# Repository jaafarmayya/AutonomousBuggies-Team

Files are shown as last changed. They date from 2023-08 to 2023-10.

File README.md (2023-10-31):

# WRO2023 FUTRE ENGINEERS - Autonomous Robot Vehicle

This repository presents a detailed description about the autonomous robot vehicle used by team 'Autonomous Buggies' in the aim of participating in WRO2023 competetion - Future Engineers category. 
The mechanical, electrical, and electronic parts of the vehicle are well described and provided. The source codes used to program the vehicle are written in Python and Arduino C. Additionally, a detailed explanation of the algorithms and mathematical principles is provided to help everyone learn. All these details can be found the sections listed below:

---

## Introduction

This Repository contains all necessary information to entirely build a self driving car, which is capable of completing three laps and
handling different configurations of the obstacles. The code is divided into two main parts, one written with python programming language, which is responsible for image processing and sending made decision to the arduino via Serial communication ([Python code](https://github.com/jaafarmayya/AutonomousBuggies-Team/tree/main/src/Obstacle%20Challenge/Python)). And one written with Arduino C programming language, which is responsible for controlling the motors movement based on the different sensors reading and recieved decision ([Arduino code](https://github.com/jaafarmayya/AutonomousBuggies-Team/tree/main/src)). The rest of the readme.md file explains in deteails each of the following:

- [Software Setup](#SoftwareSetup)
- [Mobility Management](#MobilityManagement)
- [Obstacle Management](#ObstacleManagement)
- [Power and Sense Management](#PowerandSenseManagement)

---

## Software Setup 

Before using the robot, software should be configured first, you will need to install the following (Programs have been tested and configured with both Windows 10 and Windows 11 operating systems. In case of using another operating system, we strongly recommend using any available searching engine to search for the installation for the software by yourself).
We'll be using Raspberry Pi to run image processing code written in python programming language. Commands will be sent via Serial communication to arduino wich will control the motors.

### Raspberry Pi Preparation and Configuration
In this section, we will go through all the steps to prepare and configure your Raspberry Pi. After completing the steps, you will be able to access your Raspberry Pi remotely and control it.
#### Raspberry Pi Operating System 
There are a lot of OS systems for Raspberry Pi with different versions. You can choose any of them from [official site](https://www.raspberrypi.com/software/operating-systems/), but it is preferable to install the same version we installed since it is tested and it works fine ([download link](https://downloads.raspberrypi.com/raspios_full_arm64/images/raspios_full_arm64-2023-02-22/2023-02-21-raspios-bullseye-arm64-full.img.xz)).
#### Raspberry Pi Imager installation
You will be setting up Raspberry Pi OS on your Raspberry Pi using the Raspberry Pi Imager tool, it will allow you to flash the image onto a USB flash drive. The provided steps cover the installation process, initial configuration, and essential steps to get your Raspberry Pi up and running. 
Using the Raspberry Pi Imager tool to flash the Raspberry Pi OS image onto a USB flash drive offers a convenient and efficient way to set up your Raspberry Pi. The Imager simplifies the installation process by providing a user-friendly interface to select the operating system and target storage medium. With just a few clicks, you can download the official Raspberry Pi OS image and write it directly to the USB flash drive. This eliminates the need for manual installation and configuration, saving you time and effort.
- To install Raspberry Pi Imager, Visit the official Raspberry Pi website at https://www.raspberrypi.org/software/.
- Download the Raspberry Pi Imager tool suitable for your operating system (Windows, macOS, or Linux).
- Install Raspberry Pi Imager on your computer by following the provided instructions.
####Flashing the Raspberry Pi OS Image to USB
After downloading Raspberry Pi OS and installing the Imager, you can flash the OS Image to your USB (SD card can also be used):
 - Launch Raspberry Pi Imager on your machine.
 - In the Raspberry Pi Imager window, click on "Choose OS" button.
 - Click on "Use custom" option, then navigate to the directory of the OS that was previously downloaded.
 - Click on "Choose  Storage" option, in the file explorer window select your USB flash drive as the target storage medium.
 - The widnow should have the same configuration as the image below after choosing the flash drive and OS:
     
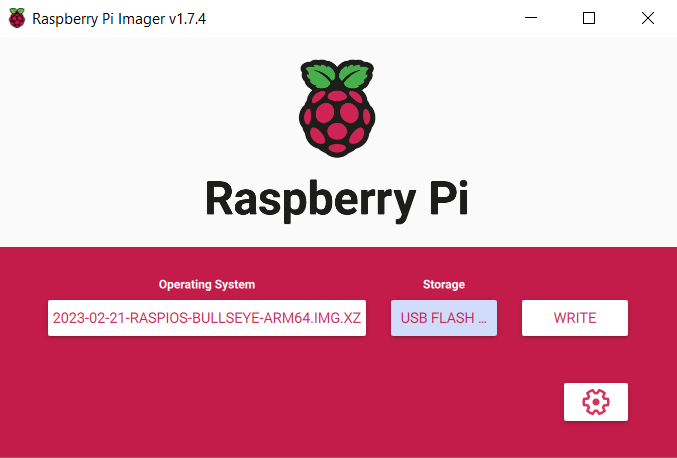
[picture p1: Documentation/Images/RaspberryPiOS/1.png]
      <p align="center" Style="font-size:12px; color:grey; font-type:italic;"><i> Figure 1: RaspberryPi Imager </i></p>

 - Now click on the settings icon in the bottom right corner, you will need to enable the SSH option and choose a username and a password (This is necessary because you will use SSH to establish a connection between your device and Raspberry Pi, it will allow you to control the Raspberry Pi remotely).

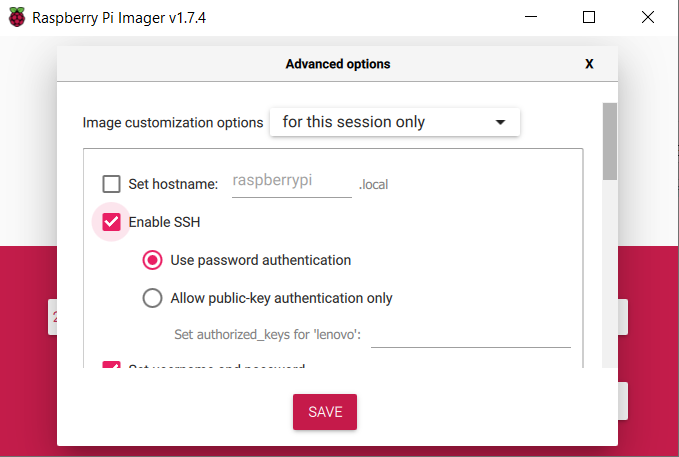
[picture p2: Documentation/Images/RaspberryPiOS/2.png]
  <p align="center" Style="font-size:12px; color:grey; font-type:italic;"><i> Figure 2: RaspberryPi SSH connection enabling </i></p>
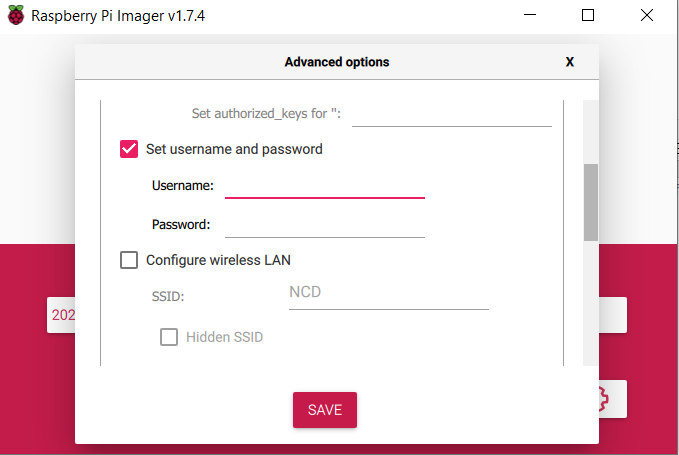
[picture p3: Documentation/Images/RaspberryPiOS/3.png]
  <p align="center" Style="font-size:12px; color:grey; font-type:italic;"><i> Figure 3: RaspberryPi username and password </i></p>

- Next, you will need to enter the name of your network and its password, this will allow you to access the Raspberry pi directly and remotely.
   
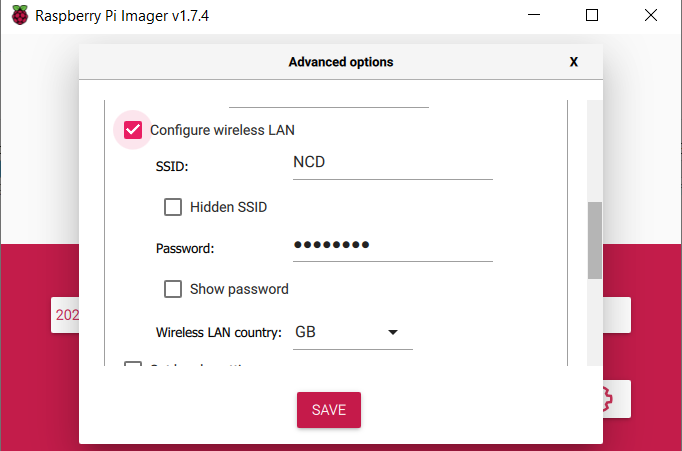
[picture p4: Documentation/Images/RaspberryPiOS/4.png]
   <p align="center" Style="font-size:12px; color:grey; font-type:italic;"><i> Figure 4: RaspberryPi network configuration </i></p>

- Click on the "Write" button to start the flashing process. Raspberry Pi Imager will download the latest Raspberry Pi OS image and write it to the USB flash drive. This process may take several minutes, depending on your machine.
Once the flashing process is completed, Raspberry Pi Imager will display a success message.

### Raspberry Pi Remote Connection configuration
There three ways to control Raspberry Pi:
- Use a mouse, a monitor and a keyboard attached to your Raspberry Pi.
- Use ethernet cable attached to your machine and Raspberry Pi, and a virutal machine software.
- Connect both Raspberry Pi and your machine to the same network, and use a virtual machine software.

we will be using the third option since it is be a lot easier to control your Raspberry Pi remotely.
1. To control and access the Raspberry Pi, you will need a program to establish wireless connection. MobaXterm is the program that will allow you to establish this communication, which is based on SSH protocol.
 - Download the program from this [link]( https://mobaxterm.mobatek.net/download-home-edition.html), choose portable edition.
 - After succefully downloading the software, extract the contents of the downloaded file to a specified folder.
 - The program is ready to be used now, when launching it, a window like that will appear (it should be noted that both the raspberry pi and your device have to be connected to the same network):

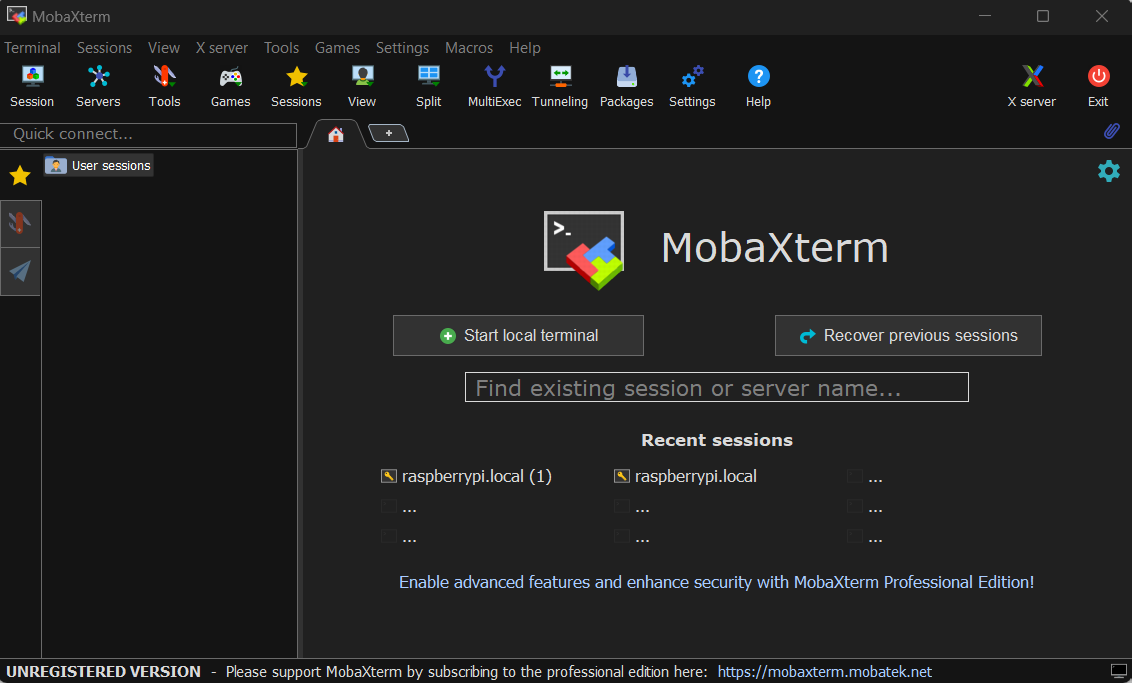
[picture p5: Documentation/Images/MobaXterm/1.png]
MobaXterm
   <p align="center" Style="font-size:12px; color:grey; font-type:italic;"><i> Figure 5: MobaXterm Interface </i></p>

 - Choose Session tab in the top left corner:

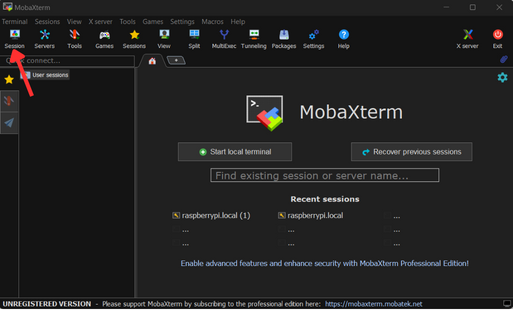
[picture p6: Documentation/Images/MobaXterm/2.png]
Session Option
   <p align="center" Style="font-size:12px; color:grey; font-type:italic;"><i> Figure 6: Choosing new session </i></p>

 - A new window will appear that contains the settings of the new connection:

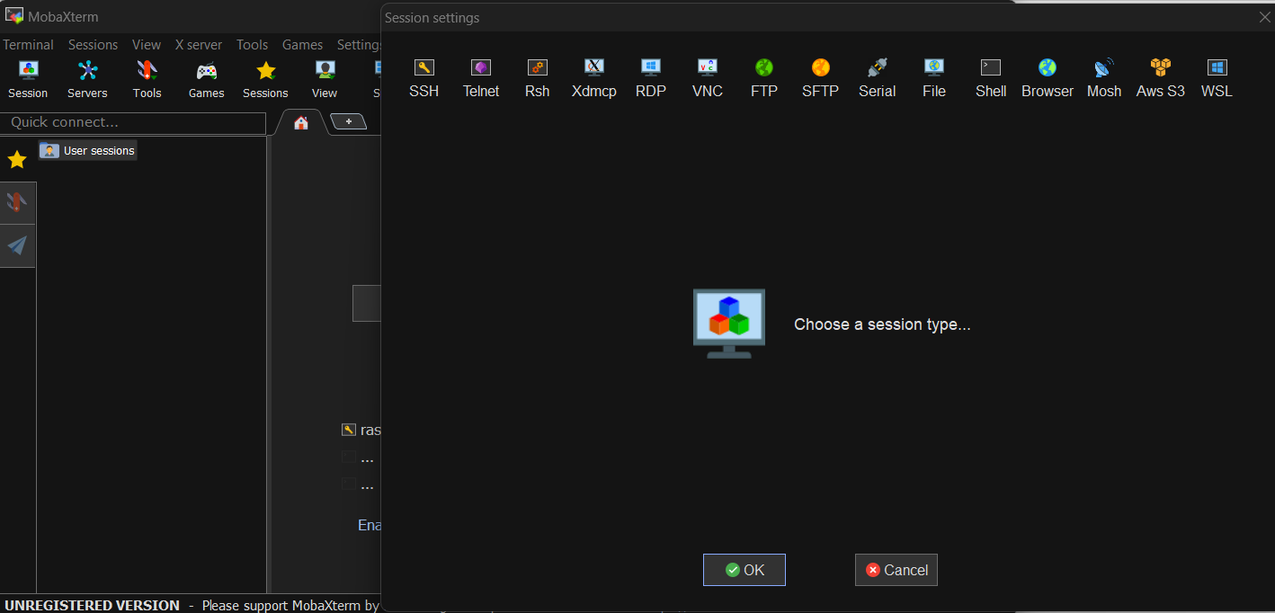
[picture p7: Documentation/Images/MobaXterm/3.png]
Session window
   <p align="center" Style="font-size:12px; color:grey; font-type:italic;"><i> Figure 7: new session tab </i></p>

 - Click on the SSH icon, we will be using SSH in our work. SSH (Secure Shell) is a network protocol that provides a secure way to access and manage remote systems. It allows to establish a secure encrypted connection between local computer and a remote device, such as a Raspberry Pi in our case.Using SSH to access a Raspberry Pi offers several advantages, as it allows remote access to the Raspberry Pi's command-line interface, providing a convenient and efficient way to manage and configure the device. Through an SSH connection, commands can be executed, files can be transfered, perform system administration tasks without the need for physical access to the Raspberry Pi. Moreover, SSH is particularly useful for headless Raspberry Pi setups, where the device is not connected to a monitor or keyboard. In such cases, SSH enables remote administration, making it possible to configure and control the Raspberry Pi over the network from a different computer.

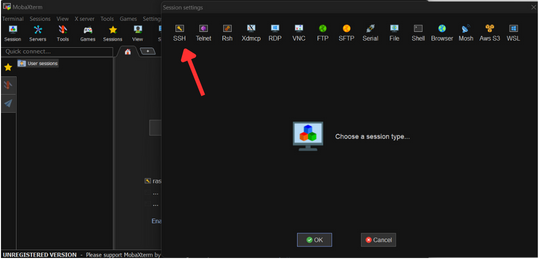
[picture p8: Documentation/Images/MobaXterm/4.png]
SSH
   <p align="center" Style="font-size:12px; color:grey; font-type:italic;"><i> Figure 8: choosing SSH communication  </i></p>

- To establish a connection with the Raspberry Pi, remte host name will be needed, which will be raspberrypi.local (The IP of the Raspberry Pi can also be used, but the domain name raspberrypi.local will work fine). With current Configuration, all commands will be executed through the terminal, to make these operations easier, LXDE desktop will be used as GUI as in the image below:

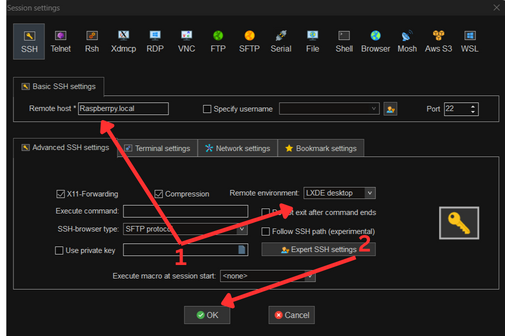
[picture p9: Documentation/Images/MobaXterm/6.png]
   <p align="center" Style="font-size:12px; color:grey; font-type:italic;"><i> Figure 9: Remote Host and LXDE Desktop</i></p>

- Now the settings are ready, click ok and it will need the username and password that was set during the setup of the raspberrypi py operating system:

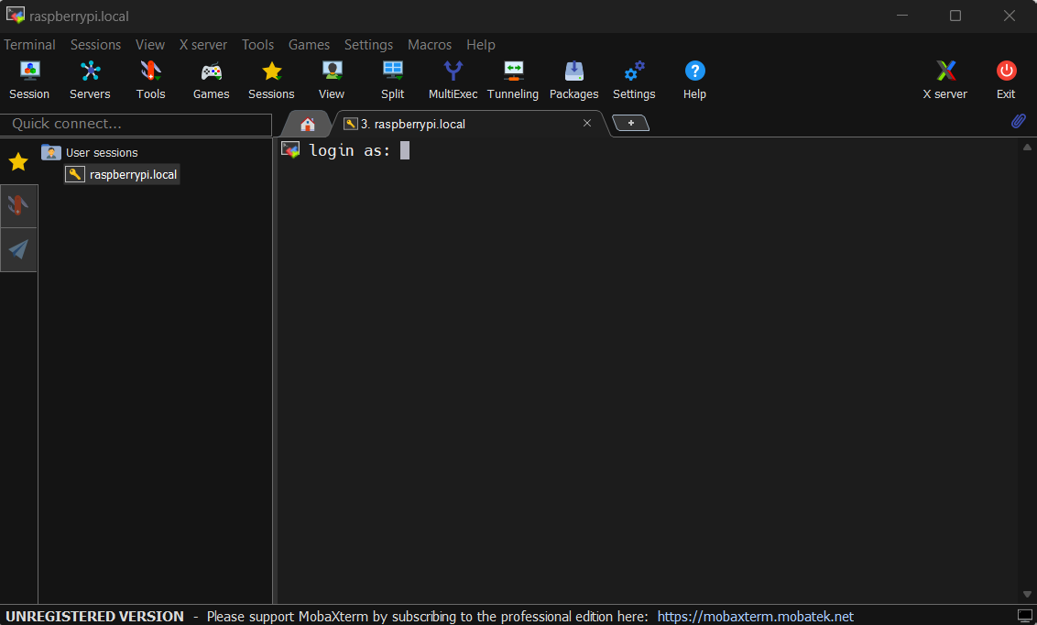
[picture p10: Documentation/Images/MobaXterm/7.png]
   <p align="center" Style="font-size:12px; color:grey; font-type:italic;"><i> Figure 10:Login window </i></p>

- After applying the previous steps, connection is succefully established and Raspberry Pi is ready to be used remotely, a new LXDE desktop window will be opened, all subsequent work will be done here:
  
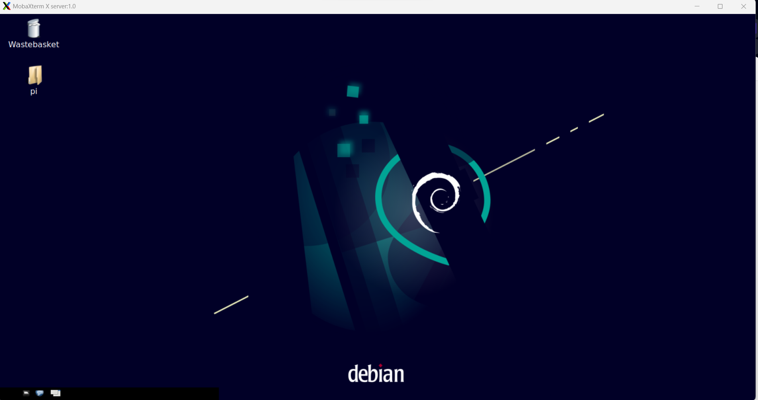
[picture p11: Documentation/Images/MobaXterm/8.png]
   <p align="center" Style="font-size:12px; color:grey; font-type:italic;"><i> Figure 11: RaspberryPi LXDE desktop </i></p>

- Update Raspberry Pi, enter the following commands in order, this step make take some time:

   1- ```sudo apt update``` 

   2- ```sudo apt upgrade```

### Raspberry Pi Camera Activation

- One last step is to turn on Raspberry Pi camera. Write the command below in the terminal:

   ```sudo raspi-config```

- The window of Raspberry Pi settings will be opened, use arrow keys to move the cursor between the options. Choose the option with label "Interfacing Options" by pressing "Enter" key:

  ![MobaXterm](/Documentation/Images/RaspberryPiOS/cam1.png)<p align="center" Style="font-size:12px; color:grey; font-type:italic;"><i> Figure 12: Interfacing Options </i></p>

- Now choose camera and press "Enter", the camera is activated now.
  
    ![MobaXterm](/Documentation/Images/RaspberryPiOS/cam2.png)

    ![MobaXterm](/Documentation/Images/RaspberryPiOS/cam3.png)<p align="center" Style="font-size:12px; color:grey; font-type:italic;"><i> Figure 13+14:Choosing camera option </i></p>

- After finishing the previous steps, press "ESC" to return to the original terminal, and enter the command below:
 
  ```sudo reboot```

### Installing Arduino IDE on Raspberry Pi

- Arduino IDE installation steps are straightforward. Open the terminal by clicking on the terminal icon or by using the shortcut Ctrl+Alt+T, then enter the following command:

   ```sudo apt install arduino```

- Before using the IDE, setting the permissions for the Arduino port in Raspberry Pi is needed:
Connect the Arduino to the Raspberry Pi using a USB cable. In the terminal on the Raspberry Pi, type the following command to list the available ports on your Raspberry Pi:
  
   ```ls /dev/tty*```

- This command will display a list of devices, and the Arduino port should be listed as something like `/dev/ttyACM0` or `/dev/ttyUSB0`. Note down the port name as you will need it for the next step. By default, the serial ports in Raspberry Pi are not accessible to regular users. To grant access to the Arduino port, you can use the chmod command to change the permissions of the port. Run the following command, replacing /dev/ttyACM0 with the actual port name you obtained:

   ```sudo chmod a+rw /dev/ttyACM0```

- After running the chmod command, you should now have the necessary permissions to access the Arduino port, and you are ready to use the arduino with the raspberry pi. To use the Arduino IDE, you can easily access it in the programming tab as in the image below:
   
   ![Settings Configuration](/Documentation/Images/MobaXterm/34.png)<p align="center" Style="font-size:12px; color:grey; font-type:italic;"><i> Figure 15:Open programming tab and click Arduino icon </i></p>

- A window will open like the one below:

   ![Settings Configuration](/Documentation/Images/MobaXterm/11.png)<p align="center" Style="font-size:12px; color:grey; font-type:italic;"><i> Figure 16:Ardunio IDE interface</i></p>

### Downloading OpenCV PySerial library

- PySerial library is essntial component to establish a succeful connection between Arduino and Raspberry Pi, it can be easily downloaded using the following command below:

   ```sudo apt-get install python-serial```

### Downloading OpenCV library on Raspberry Pi

We will be using OpenCV library, which stands for (Open Source Computer Vision Library). OpenCV is a popular open-source computer vision and machine learning library. It provides a vast collection of functions and algorithms for image and video processing, object detection and tracking, feature extraction, and more.

- OpenCv library isn't installed by default on the Raspberry Pi, you will have to install it. Open the terminal, and type the following command:

   ``` sudo apt-get install python3-opencv```
- Wait till the installation is done, when it is done, open any code editor, which can be found in the programming tab:
  
     ![Settings Configuration](/Documentation/Images/MobaXterm/34.png)<p align="center" Style="font-size:12px; color:grey; font-type:italic;"><i> Figure 17:Open programming tab and click Geany icon</i></p>

- Choose Geany code editor for example. Geany is a simple and easy to use code editor (Try searching the internet for more details in case you want to know more), a window like this will be opened:
  
     ![Settings Configuration](/Documentation/Images/MobaXterm/9.png)<p align="center" Style="font-size:12px; color:grey; font-type:italic;"><i> Figure 18:Geany editor interface </i></p>

- Import the library using the following command, and you are ready to use the library:

   ```import cv2```

---

##Mobility Management 

### Vehicle Main Body
The vehicle main body is built using `LEGO`, building instructions are available [here](https://github.com/jaafarmayya/AutonomousBuggies-Team/blob/main/models/Building%20Instructions.rar).
The main Micrprocessor in the vehicle is `Raspberry Pi 4 Model b` provided with `Raspberry pi Camera V2.1`.
Main Macrocontroller is Atmega mounted on `Arudino Mega 2560` board.
To ensure the accurate and efficient control and direction of the vehicle’s movement, we employed two crucial components:
- **Servo Motor Model**
- **J Sumo DC Motor**
- **BTS7960 Motor Driver**

The servo motor model was selected for controlling the vehicle’s steering, while the BTS7960 motor driver is utilized to control the movement of J Sumo DC motor in order to provide the necessary power to drive the vehicle’s motion. 

### The Motion Mechanism 
We used Direct-Acting steering and to achieve that a servo motor was installed in way that can move the steering mechanism freely, while the DC motor (J Sumo 1000 rpm) serves as the driving motor. The kinetic energy generated by the DC motor is transferred to the back wheels through a differential gearbox. The wheels receive this energy via a drive shafts of LEGO components, which transmits torque to the differential gearbox through a suitable coupler [model](https://github.com/jaafarmayya/AutonomousBuggies-Team/blob/main/models/Coupler.jpg).

### Steering Mechanism

Our design incorporates front Direct-Acting Steering, a mechanism that eliminates the need for a steering gear by connecting the steering wheel directly to the steering linkage. Our front direct-acting steering method offers several advantages over conventional steering systems:

**A.Enhanced Responsiveness:**
The direct connection between the steering wheel and the steering linkage results in immediate and precise response to servo's input (angle), providing enhanced control and maneuverability.

 **B.Reduced Complexity:**
Our steering method simplifies the overall design, reducing weight and complexity, and potentially lowering manufacturing and maintenance costs.

**C. Lower Maintenance Requirements:**
 With fewer components involved, the direct-acting steering method can reduce the need for maintenance and potential points of failure, resulting in improved reliability and durability.
The mechanism of our front direct-acting steering method can be summarized as follows:

**-  Steering Input Translation:**
 When the servo motor turns the steering axle, the input is directly transmitted to the steering linkage, causing the front wheels to turn accordingly.

**-  Cornering:**
 During cornering, the steering mechanism maintain a smooth trajectory based on the servo motor input.

![Direct Acting Steering](/Documentation/Images/Steering+Mechanism/Picture1.jpg)

![Direct Acting Steering](/Documentation/Images/Steering+Mechanism/SteeringMechanism.jpg)<p align="center" Style="font-size:12px; color:grey; font-type:italic;"><i> Figure 19:Direct Acting Steering </i></p>

When designing a steering mechanism, some parameters should be considered to measure the characteristics and specifications of the steering system:

**1. Steering Ratio**

It is a key parameter in a steering system that describes the relationship between the rotation of the steering wheel (which is servo axle in our case) and the resulting rotation of the wheels. Moreover, it quantifies the mechanical advantage or amplification provided by the steering mechanism.
Mathematically speaking, it is defined as the ratio of the angle turned by the steering wheel (servo axle) θ<sub>servo</sub> 
to the angle turned by the wheels θ<sub>wheels</sub> , in the direct acting steering θ<sub>wheels</sub> is equal to θ<sub>servo</sub>.
It can be expressed as:

$\theta _{servo} =  \theta _{wheels}  \Rightarrow Steering Ratio =  \frac{\theta _{servo}}{\theta _{wheels}} = 1$

The steering ratio determines how much the wheels will turn in response to a given rotation of the servo. A higher steering ratio means that a smaller rotation of the steering wheel will result in a larger rotation of the wheels, providing a greater turning effect. Conversely, a lower steering ratio means that a larger rotation of the steering wheel is required to achieve the same wheel rotation. So, it can be described as a measure of the sensitivity and responsiveness of the steering system.

**2. Steering Wheel Torque**
 
Steering wheel torque T<sub>wheels</sub>
is the influence of servo motor force or moment applied on the steering. In other words, it refers to the force or moment applied to the wheels as a result of the torque output from the servo motor.
T<sub>wheels</sub> can be calculated by multiplying the applied force by servo motor F<sub>servo</sub> by the effective lever arm or steering arm length L<sub>eff</sub> which is the distance between the point where the force is applied and the axis of rotation of the steering wheel: 

$T_{wheel} =  F_{servo}  \times L_{eff}$

When interpreting the steering wheel torque, it should be noted that a higher steering wheel torque indicates that more force is needed from the servo motor to turn the steering wheel, providing a greater resistance to steering. Conversely, a lower steering wheel torque implies that less force is required, resulting in lighter and easier steering.

**3. Steering Wheel angle**

The steering wheel angle refers to the angle of rotation of the servo motor's output shaft, which is directly connected to the steering mechanism of the robot. Furthermore, it represents the angular displacement of the servo motor's output shaft from its neutral or reference position. 
This angle determines the orientation of the robot's steering mechanism and thus influences the robot's movement and direction.

$\theta_{wheel} =  \theta_{motor}  \times Steering Ratio$

---

### Differential Gear
Differential gear is a crucial component in our robot that allows the rear-wheels to rotate at different speeds at the same time while maintaining power distribution. The primary function of the differential gear is to enable the wheels on the same axle to rotate at different speeds when the robot is turning or when there is a difference in traction between the two wheels. It distributes torque from the engine to the wheels while allowing them to rotate at varying speeds. Our differential gear consists of several components:
- Ring Gear: A large gear attached to the axle shaft that receives power from the engine or the driveshaft.
- Pinion Gear: A smaller gear connected to the drive shaft, which meshes with the ring gear.
- Side Gears: Two gears that connect the differential to the axle shafts.
- Spider Gears: These gears are positioned between the side gears and allow the wheels to rotate at different speeds.

When the vehicle is moving in a straight line, the differential distributes torque equally to both wheels. However, when the vehicle turns, the inside wheel (closer to the center of rotation) needs to rotate at a slower speed than the outside wheel to prevent slippage. The differential allows this speed difference by allowing the side gears to rotate at different speeds while maintaining power distribution.
It is important to determine gear ratio before designing a differential gear, which involves understanding the specifications and characteristics of the motors, as well as the mechanical setup of the differential. To calculate the differential gear ratio, the ratio between the ring gear and the side gears should be determined. This can be done by counting the number of teeth on each gear:
   - The number of teeth on the ring gear (crown wheel). Let's call it $R$
   - The number of teeth on each side gear (sun gear). Let's call them $S1$ and $S2$
The differential gear ratio can be calculated as the ratio between the teeth on the ring gear and the teeth on one side gear. Since there are two side gears in the differential, the gear ratio is multiplied by 2:  

$Gear Ratio =  \frac{2  \times R}{ S_{1} } = \frac{2  \times R}{ S_{2} }$

The gear ratio represents the rotational speed and torque distribution between the two side gears of the differential. 
Once the gear ratio calculation is done, motor speed can be related to the wheel speed. Since the side gears are connected to the wheels, their speed is directly proportional to the wheel speed. The no-load speed of the motor N<sub>MotorNoLoad</sub> from the motor's specifications, which will enable us to calculate the wheel speed using the formula:

$N_{wheel} =  \frac{N_{MotorNoLoad}}{Gear Ratio}$

The wheel speed represents the rotational speed of the LEGO differential's side gears, which directly affects the vehicle's speed. However, the calculated values may need to be calibrated when experimenting them (Real world values may differ from the calculated ones due to multiple constraints that can’t be considered when doing the calculations). However, the results and objectives of our design showed no need to the calibration.

The following diagram represents the steps of calculating the $N_{wheel}$ with respect to the $N_{MotorNoLoad}$ and the $Gear Ratio$:

![Flow Chart](/Documentation/Images/Steering+Mechanism/Correct1.png)<p align="center" Style="font-size:12px; color:grey; font-type:italic;"><i> Figure 20:Calculation flowchart of N_wheel, gear ratio and N_MotorNoLoad </i></p>

![Illustrated Differential Gear Box](/Documentation/Images/Steering+Mechanism/Correct2.png)<p align="center" Style="font-size:12px; color:grey; font-type:italic;"><i> Figure 21:Differential gear box </i></p>

--- 

## Motor Driver

A motor driver is crucial for controlling motors as it enables the safe handling and delivery of the required power to drive the motor, while also providing protection features to prevent damage in abnormal operating conditions. Furthermore, it offers precise control, speed, direction, and acceleration, so a driver are essential for applications that require accurate positioning or motion control as in our case. It offers bidirectional control, compatibility with different motor types, and optimize power usage for improved system efficiency. We tested two types of them in our robot.

![Controller_Driver_Motor](/Documentation/Images/PowerAndSense/Controller_Driver_Motor.png)<p align="center" Style="font-size:12px; color:grey; font-type:italic;"><i> Figure 22:Motor controlling open loop</i></p>

---

### Wheels

Lego wheels were used in the robot's design, their advantage comes from their efficiency and light weight. The table below clarify the specifications of the wheels.

| Lego Wheel Specifications (Part ID: 56908 / 41897) | Value                                               |
| ------------------------------------------------- | --------------------------------------------------- |
| Total diameter                                   | 56 mm (2.2'')                                       |
| Tire width                                       | 28 mm (1.1'')                                       |
| Rim diameter                                     | 43 mm (1.69'')                                      |
| Rim width                                        | 26 mm (1.02'')                                      |
| Weight                                           | 23g                                                 |
| Rim material                                     | ABS (Acrylonitrile Butadiene Styrene)               |
| Tire material                                    | SEBS (Styrene-Ethylene Ethylene-Butylene-Styrene)   |
<p align="center" Style="font-size:12px; color:grey; font-type:italic;"><i> Table 1: LEGO Wheels Specifications </i></p>

![LEGO Wheel](/Documentation/Images/Steering+Mechanism/Wheel.jpg)<p align="center" Style="font-size:12px; color:grey; font-type:italic;"><i> Figure 23:Lego wheels </i></p>

### Lego Axles
Using LEGO axles (4.8mm Diameter) in both differential gears mechanism and wheels connecting significantly improves the robot’s efficiency. LEGO axles provide precise rotational motion, and minimize friction and energy losses. It is made of PA (Polyamide) which is a type of material that can withstand high loads and impacts. This means it’s suitable for elements that need to be tough and able to interact with each other, ensuring smooth power transmission and prolonged operation, for example, gearwheels and different connectors.

![Steering Axle](/Documentation/Images/Steering+Mechanism/Steering.jpg)
<p align="center" Style="font-size:12px; color:grey; font-type:italic;"><i> Figure 24: LEGO Axle </i></p>

---

### Coupler Design:
Power transmission plays a critical role in ensuring efficient and reliable movement. We utilized a coupler to transfer torque from a Jsumo DC motor to a LEGO axle and also another coupler to transmit torque from a servo motor to the steering LEGO axle. This solution combines the flexibility and customization of 3D manufacturing with the versatility and precision of LEGO components, resulting in a robust and seamless power transmission mechanism. The coupler acts as the mediator between motors and the LEGO axles, seamlessly connecting both components while maintaining torque transfer efficiency. The design of the coupler is carefully engineered to fit snugly onto the motor shaft and securely attach to the LEGO axle, ensuring optimal power transmission without slippage or loss. This design can be produced using 3D Printers or CNC Cutting Machine.

**The figure shows the design of the coupler:**
![3D printed coupler](/Documentation/Images/couplers/coupler.jpg)
<p align="center" Style="font-size:12px; color:grey; font-type:italic;"><i> Figure 25: Coupler Drawings (extracted from CATIA V5)  </i></p>

## Power & Sense Management 

We used 2 Li-poly RC Batteries (12V – 2200mAh) as a source of power. The first one supplies
the Arduino Board, Sensors, Servo motor, and DC motor; the second one supplies the Raspberrypi microprocessor. The robot is power supplied by two batteries as we mentioned before. The
   distribution of power is done by Three RioRand step-down DC-DC Converter that take their input
   from the batteries directly (12V input) and convert this input to (5V output). The first one supplies
   the raspberry pi microprocessor and its cooling fan. The second gives supply to a “bridge” which
   in turn supply the sensors and the gyroscope. The third supplies the servo motor. The DC motor
   is supplied via BTS motor driver that’s supplied directly from the batteries.
   We used 2 Li-poly RC Batteries (12V – 2200mAh) as a source of power. The first one supplies 
   the Arduino Board, Sensors, Servo motor, and DC motor; the second one supplies the Raspberry
   pi microprocessor. The robot is power supplied by two batteries as we mentioned before. The
   distribution of power is done by Three RioRand step-down DC-DC Converter that take their input
   from the batteries directly (12V input) and convert this input to (5V output). The first one supplies
   the raspberry pi microprocessor and its cooling fan. The second gives supply to a “bridge” which
   in turn supply the sensors and the gyroscope. The third supplies the servo motor. The DC motor
   is supplied via BTS motor driver that’s supplied directly from the batteries.

### Electronic Components
- **Arduino Mega 2560:** [[2]](https://store.arduino.cc/products/arduino-mega-2560-rev3) The Arduino Mega 2560 is an open-source microcontroller board based on the ATmega2560 microcontroller. It is one of the most popular boards in the Arduino family due to its versatility and extensive I/O capabilities. The Mega 2560 is designed to offer a large number of digital and analog inputs and outputs, making it suitable for complex projects that require multiple sensors, actuators, and communication interfaces. The key features and specifications of the Arduino Mega 2560:

   1. Microcontroller: The Mega 2560 is powered by the ATmega2560 microcontroller, which has 256KB of flash memory for storing code, 8KB of SRAM for data storage, and 4KB of EEPROM for non-volatile storage.

   2. Digital I/O Pins: The board offers 54 digital I/O pins, of which 15 can be used as PWM outputs. These pins can be used for connecting various components such as sensors, switches, LEDs, and other digital devices.

   3. Analog Inputs: The Mega 2560 has 16 analog inputs, allowing you to read analog signals from sensors and other devices. These inputs have a 10-bit resolution, providing 1024 different voltage levels.

   4. Communication Interfaces: The board supports multiple communication interfaces, including UART (Universal Asynchronous Receiver/Transmitter), SPI (Serial Peripheral Interface), and I2C (Inter-Integrated Circuit). These interfaces enable communication with other devices such as sensors, displays, and modules.

   5. USB Interface: The Mega 2560 features a USB interface that allows it to be connected to a computer for programming and serial communication. It can appear as a virtual serial port for easy integration with software development environments.

   6. Operating Voltage: The board operates at 5V, making it compatible with a wide range of sensors, modules, and other components.

   7. Memory Expansion: The Mega 2560 supports external memory expansion through an optional SD card slot, allowing you to store larger amounts of data or log sensor readings.

   8. Compatibility: The Mega 2560 is fully compatible with the Arduino software and programming language, making it easy to get started with coding and prototyping.

   9. Shield Compatibility: The board is designed to be compatible with Arduino shields, which are additional modules that can be stacked on top of the board to extend its functionality. This allows you to easily add features such as Wi-Fi, Bluetooth, motor control, and more.  

     ![Ardunio](/Documentation/Images/PowerAndSense/Arduino.jpg)
  <p Style="font-size:12px; color:grey; font-type:italic;"><i> Figure 26: Arduino Mega2560</i></p>

- **Raspberry pi 4 Model B:** [[3]](https://www.raspberrypi.com/products/raspberry-pi-4-model-b/) The Raspberry Pi 4 Model B is a popular single-board computer (SBC) developed by the Raspberry Pi Foundation. It is the fourth generation of the Raspberry Pi series and offers significant improvements over its predecessors. The Raspberry Pi 4 Model B is designed to be a versatile and affordable platform for various applications, including education, prototyping, home automation, media centers, and more. The key features and specifications of the Raspberry Pi 4 Model B:
   1. Processor: The board is powered by a Broadcom BCM2711 quad-core Cortex-A72 (ARMv8) 64-bit system-on-a-chip (SoC) running at 1.5 GHz. This processor provides a significant performance boost compared to previous Raspberry Pi models, enabling smoother multitasking and faster execution of applications.

   2. Memory: The Raspberry Pi 4 Model B is available in different memory configurations, including 2GB, 4GB, and 8GB LPDDR4 RAM options. The increased memory capacity allows for better performance, especially when running resource-intensive applications or multitasking.

   1. GPU: It features a VideoCore VI GPU, which supports OpenGL ES 3.x and 4Kp60 hardware decode of HEVC video. The GPU enables multimedia applications, gaming, and hardware-accelerated video playback.

   1. Connectivity: The board offers improved connectivity options, including:
     * Gigabit Ethernet: Provides fast wired network connectivity.

     * Dual-band Wi-Fi: Supports 2.4 GHz and 5 GHz wireless networks, offering improved wireless performance.
     * Bluetooth 5.0: Enables wireless connectivity with Bluetooth-enabled devices.
     * USB Ports: The Raspberry Pi 4 Model B has two USB 2.0 ports and two USB 3.0 ports, allowing for easy connection of peripherals such as keyboards, mice, external drives, and more.
   5. Video and Display: The Raspberry Pi 4 Model B supports dual-monitor output with resolutions up to 4K. It features two micro HDMI ports, allowing you to connect two displays simultaneously. The board also has a MIPI DSI display port and a MIPI CSI camera port for connecting touchscreens and cameras.

   1. Storage: It includes a microSD card slot for the operating system and data storage. Additionally, it has two USB 3.0 ports and two USB 2.0 ports, which can be used to connect external storage devices such as hard drives or USB flash drives.

   1. GPIO Pins: The board maintains compatibility with previous Raspberry Pi models and provides 40 GPIO (General Purpose Input/Output) pins, which allow for the connection of various sensors, actuators, and other electronic components.

   1. Operating System: The Raspberry Pi 4 Model B is compatible with a wide range of operating systems, including Linux distributions such as Raspbian (now known as Raspberry Pi OS), Ubuntu, and others. This flexibility enables developers to choose the OS that best suits their needs and leverage the extensive software ecosystem available for the Raspberry Pi. 
    
     ![RaspberryPi](/Documentation/Images/PowerAndSense/RaspberryPi.jpg)
  <p Style="font-size:12px; color:grey; font-type:italic;"><i> Figure 27: RaspberryPi</i></p>

- **Raspberry pi camera:** [[4]](https://www.raspberrypi.com/products/camera-module-v2/) The Raspberry pi camera was used to discover the playfield of the robot and to detect the color of the pillars existed in front of the vehicle. 

     ![PiCamera](/Documentation/Images/PowerAndSense/Camera.jpg)
  <p Style="font-size:12px; color:grey; font-type:italic;"><i> Figure 28: RaspberryPi Camera</i></p>

- **BTS7960 Motor Driver:** [[5]](https://uk.farnell.com/c/sensors-transducers/sensors/ultrasonic-sensors)
    The BTS7960 Motor Driver is a popular dual H-bridge motor driver module that allows you to control the speed and direction of DC motors. It is commonly used in robotics, automation, and other projects that require precise motor control.
    The key features and specifications of the BTS7960 Motor Driver:

    **i.H-Bridge** Configuration: The BTS7960 Motor Driver utilizes an H-bridge configuration, which consists of four power MOSFETs (Metal-Oxide-Semiconductor Field-Effect Transistors) arranged in pairs. This configuration enables bidirectional control of the motor, allowing you to control its rotation in forward and reverse directions.

    **ii.Motor Compatibility:** The motor driver module is designed to work with DC motors and can handle a wide range of motor voltages, typically between 5V and 27V. The maximum continuous current per channel is typically around 43A, making it suitable for driving high-power motors.

    **iii.Current Sensing:** The BTS7960 Motor Driver features built-in current sensing capabilities. It has two current sense pins that allow you to monitor the current flowing through each motor channel. This feature can be useful for various purposes, such as implementing motor current protection or feedback control.

    **iiii.PWM Control:** The motor driver supports Pulse Width Modulation (PWM) control for speed regulation. By varying the duty cycle of the PWM signal, you can adjust the motor's speed precisely. The module accepts a PWM input signal from a microcontroller or any other PWM source.

    **iv.Overcurrent and Overtemperature Protection:** The BTS7960 Motor Driver incorporates protection mechanisms to safeguard both the driver and the motor. It includes built-in overcurrent and overtemperature protection circuits that can help prevent damage to the motor driver module and the connected motor.

    **vi.Input and Output Connections:** The motor driver module typically has separate input pins for controlling the motor direction and speed. These control pins can be connected to the digital output pins of a microcontroller or other control devices. The motor connections are made to the driver's output terminals, allowing you to connect the DC motor.

    **vii.Heat Dissipation:** Due to its high current handling capacity, the BTS7960 motor driver may generate heat during operation. To dissipate heat effectively, the module often includes a heat sink or a mounting hole for attaching an external heat sink.

    **viii.Compatibility:** The BTS7960 Motor Driver can be used with various microcontrollers, such as Arduino, Raspberry Pi, or any other microcontroller capable of generating the necessary control signals for the driver module.
    
     ![BTS7960](/Documentation/Images/PowerAndSense/BTS7960.jpg)
  <p Style="font-size:12px; color:grey; font-type:italic;"><i> Figure 29: BTS7960 Motor Driver</i></p>

- **L298N Motor Driver:**

    The L298N Motor Driver is another widely used motor driver module that provides control over the speed and direction of DC motors. It also utilizes an H-bridge configuration, consisting of four power transistors arranged in pairs, enabling bidirectional control of the motor's rotation.

    **i.H-Bridge Configuration:** The L298N utilizes a dual H-bridge motor driver that allows speed and direction control of two DC motors at the same time, this configuration
    contains four switching elements, transistors or MOSFETs, with the motor at the center. It also has two switches that can be used to control the motor rotation in either direction. Moreover, the input pins of the L298N are used for controlling the rotation direction of the motor A and B, and by controlling these pins, the switches of the H-Bridge inside the L298N IC are controlled.

    **ii.Motor Compatibility:** The L298N Motor Driver is designed to work with DC motors and can handle a wide range of motor voltages, it is suitable for driving medium-power motors.

    **iii.Current Sensing:** The L298N Motor Driver does not have built-in current sensing capabilities, but external current sensing circuitry can be implemented separately if current monitoring is required.

    **vi.PWM Control:** The L298N Motor Driver supports PWM control for regulating the motor's speed. By adjusting the duty cycle of the PWM signal, the motor's speed can be precisely controlled.

    **v.Overcurrent Protection:** The L298N Motor Driver incorporates overcurrent protection mechanisms to prevent damage to the driver and the connected motor. However, it does not typically include built-in overtemperature protection.

    **vi.Input and Output Connections:** The motor driver module has separate input pins for controlling the motor direction and speed. These control pins can be connected to the digital output pins of a microcontroller or other control devices, while the motor connections are made to the driver's output terminals.

    **vii.Heat Dissipation:** The L298N Motor Driver may generate heat during operation due to its current handling capacity. It often includes a heat sink or a mounting hole for attaching an external heat sink to dissipate heat effectively.

    **viii.Compatibility:** The L298N Motor Driver is compatible with various microcontrollers, including Arduino, Raspberry Pi, and other microcontrollers capable of generating the necessary control signals for the driver module.
  
  ![L298N](/Documentation/Images/PowerAndSense/L298N.jpg)
  <p Style="font-size:12px; color:grey; font-type:italic;"><i> Figure 30: L298N Motor Driver</i></p>
- **Comparison between L298N and BTS7960:**

    We tested both circuits and evaluated their performance on the robot. However, BTS7960 Motor Driver showed noticably better results, on the other hand, L298N didn't meet the requirements of our robot which resulted in overheated circuit and not enough current input current to the JSumo DC Motor. Here are the key differences between both motor drivers:
    
    1. **Current Handling:** The BTS7960 Motor Driver has a higher current handling capacity compared to the L298N Motor Driver, making it more suitable for driving high-power motors (J-Sumo Motor in our case).

    2. **Current Sensing:** The BTS7960 Motor Driver includes built-in current sensing pins, allowing for easy monitoring of motor current. On the other hand, the L298N Motor Driver does not have this feature, requiring external circuitry for current sensing.

    3. **Overtemperature Protection:** The BTS7960 Motor Driver incorporates overtemperature protection, which helps safeguard the driver and the motor. The L298N Motor Driver does not typically include this protection mechanism.

    4. **Voltage Range:** The L298N Motor Driver has a wider voltage range compared to the BTS7960.

- **3 RioRand LM2596 step-down DC-DC Converter:** [[6]](https://www.amazon.com/RioRand-LM2596-Converter-1-23V-30V-5Pcs-LM2596/dp/B008BHB4L8) The RioRand LM2596 is a popular step-down DC-DC converter module based on the LM2596 switching regulator integrated circuit. It is commonly used to convert higher DC voltages to lower, more stable voltages for various electronic applications. The LM2596 module offers efficient and adjustable voltage regulation, making it widely used in projects requiring reliable power supply solutions.

  The key features and specifications of the RioRand LM2596 step-down DC-DC converter:

   1. Conversion Efficiency: The LM2596 module utilizes a switching regulator topology, which provides high conversion efficiency compared to linear regulators. It can achieve conversion efficiencies of up to 90% or more, depending on the input and output voltage differentials.

   2. Input Voltage Range: The LM2596 module can accept a wide range of input voltages, typically between 4.5V and 40V DC. This flexibility allows it to be used with various power sources, such as batteries, power adapters, or other DC power supplies.

   3. Adjustable Output Voltage: One of the key features of the LM2596 module is its ability to provide adjustable output voltage. By adjusting the onboard potentiometer or using an external voltage divider, you can set the desired output voltage within the module's specified range. The output voltage can typically be adjusted from around 1.25V to 37V DC.

   4. Output Current: The LM2596 module can handle a maximum output current of around 2A or more, depending on the specific module variant and configuration. This current rating determines the maximum load current that the module can reliably supply.

   5. Protection Features: The LM2596 module often includes built-in protection features to ensure the safety and longevity of the circuit. These features may include overcurrent protection, thermal shutdown, and input/output overvoltage protection.

   6. Heat Dissipation: Like other power electronics components, the LM2596 module may generate heat during operation. To dissipate heat effectively and maintain optimal performance, the module typically includes a heat sink or a mounting hole for attaching an external heat sink.

   7. Input and Output Connections: The LM2596 module typically has screw terminals or pin headers for easy connection to the input and output voltage sources. The input voltage is connected to the higher voltage source, while the output voltage is connected to the load or the circuit that requires the lower voltage supply.

   8. Applications: The LM2596 module finds applications in a wide range of projects, including electronics prototyping, DIY projects, power supply modules, battery charging systems, LED lighting, and more. Its adjustable output voltage and high efficiency make it a versatile choice for powering various electronic devices and circuits. 
 
 ![Dc2Dc converter](/Documentation/Images/PowerAndSense/DcDcConv.jpg)
  <p Style="font-size:12px; color:grey; font-type:italic;"><i> Figure 31: RioRand  LM2596 step-down DC-DC Converter</i></p>

* **Servo Motor:** [[7]](https://www.towerpro.com.tw/product/sg90-7/)
  + Torque: 1,6kgcm
  + Stall current 650±80mA
  + Voltage 4,8 V - 7,2 V
  + Speed 0.12 sec / 60 degrees (4.8V)
  + Gears Nylon
  + Length 22 mm
  + Width 11,5 mm
  + Height 22,5 mm Weight 16 g 

     ![Servo](/Documentation/Images/PowerAndSense/Sg.webp)
  <p Style="font-size:12px; color:grey; font-type:italic;"><i> Figure 32: Servo Motor</i></p>
- **Li-Po RC Batteries 12V:** [[8]](https://robocraze.com/products/11-1v-2200mah-25c-li-po-battery) Lithium Polymer (Li-Po) batteries are a type of rechargeable battery that are widely used due to their high energy density, lightweight, and ability to deliver high currents. It provides a good balance between capacity and weight.

  | Battery Parameter     | Value                                 |
  | --------------------- | ------------------------------------- |
  | Model                 | ZOP Power 11.1V 2200mAh 30C           |
  | Capacity              | 2200mAh                               |
  | Size                  | 28x34x116mm                           |
  | Plug Style            | XT60 Plug                             |
  | Weight                | 140g                                  |
  <p Style="font-size:12px; color:grey; font-type:italic;"><i> Table 2: LiPo Battery Specifications </i></p>

  ![Lithium Polymer (Li-Po)](/Documentation/Images/PowerAndSense/Lipo(1).jpg)
  <p Style="font-size:12px; color:grey; font-type:italic;"><i> Figure 33: LiPo 2800mAh Battery</i></p>

- **J Sumo DC Motor:** [[1]](https://www.jsumo.com/jsumo-titan-dc-gearhead-motor-12v-1000-rpm-hp)
  - The diameter of the motor is 37mm. Length is 75mm.
  - 6mm diameter shaft section, shaft length 17 mm.
  - 6 M3 screw holes on the front side are available.
  - No load current is 240ma, and stall current is 5.9 Ampere.
  - All Gearhead gears are metal.
  - Motor’s stall torque is 7.5 kg-cm.

     ![Dc](/Documentation/Images/PowerAndSense/jSumo.jpg)
  <p Style="font-size:12px; color:grey; font-type:italic;"><i> Figure 34: jSumo Dc Motor</i></p>

- **MPU 6050:** [[9]](https://www.electronicwings.com/sensors-modules/mpu6050-gyroscope-accelerometer-temperature-sensor-module) The MPU-6050 is a popular and widely used integrated circuit (IC) that combines a 3-axis gyroscope and a 3-axis accelerometer in a single package. It is commonly used in various applications such as motion sensing, orientation tracking, gesture recognition, and stabilization control systems.

  The key features and specifications of the MPU-6050:

    1. 3-Axis Gyroscope: The MPU-6050 includes a 3-axis gyroscope, which measures angular velocity around three axes (X, Y, and Z). It provides accurate motion sensing capabilities and can be used to detect rotational movements.

    2. 3-Axis Accelerometer: The MPU-6050 also incorporates a 3-axis accelerometer, which measures linear acceleration along the three axes (X, Y, and Z). It enables the detection of changes in velocity and the determination of tilt or inclination.

    3. Digital Motion Processing: The MPU-6050 features an onboard digital motion processor (DMP) that offloads motion processing tasks from the main microcontroller. The DMP performs sensor fusion, combining data from the gyroscope and accelerometer to provide accurate and reliable motion tracking information.

    4. I2C Interface: The MPU-6050 communicates with the microcontroller or other devices using the I2C (Inter-Integrated Circuit) protocol. It has an I2C interface that allows for easy integration and control with various microcontrollers and development boards.

    5. Motion Detection Interrupts: The MPU-6050 includes built-in motion detection capabilities and supports programmable interrupts. This allows the IC to generate interrupts to the microcontroller when predefined motion or orientation thresholds are met, enabling efficient and responsive operation.
 
    6. Low Power Consumption: The MPU-6050 is designed to operate with low power consumption, making it suitable for battery-powered applications and devices with power constraints.

    7. Temperature Sensor: The IC incorporates an onboard temperature sensor, providing accurate temperature measurements in addition to motion and orientation data.

    8. Applications: The MPU-6050 is widely used in applications such as robotics, drones, gaming controllers, virtual reality (VR) and augmented reality (AR) devices, inertial navigation systems, motion-controlled user interfaces, and many other projects where motion sensing and orientation tracking are required. 

     ![Mpu6050](/Documentation/Images/PowerAndSense/mpu6050.jpg)
  <p Style="font-size:12px; color:grey; font-type:italic;"><i> Figure 35: MPU6050</i></p>

- **Cooling Fan:** The cooling fan is used to cool down the temperature of the Raspberry pi microprocessor.

     ![Cooling Fan](/Documentation/Images/PowerAndSense/CoolingFan.jpg)
  <p Style="font-size:12px; color:grey; font-type:italic;"><i> Figure 36: Cooling Fan</i></p>

- **UltraSonic Sensors:** [[10]](https://uk.farnell.com/c/sensors-transducers/sensors/ultrasonic-sensors)
  Ultrasonic sensors are electronic devices that use ultrasonic waves to measure distance or detect objects. They work based on the principle of echolocation, similar to how bats navigate in the dark. Ultrasonic sensors emit high-frequency sound waves (typically above the range of human hearing) and then receive the reflected waves to determine the distance or presence of objects.

  The key characteristics and applications of ultrasonic sensors:

    1. Distance Measurement: Ultrasonic sensors are commonly used for non-contact distance measurement. They typically emit ultrasonic pulses and measure the time it takes for the sound waves to bounce back after hitting an object. By knowing the speed of sound in the medium (usually air), the sensor can calculate the distance to the object.

    2. Object Detection: Ultrasonic sensors can detect the presence or absence of objects within their range. When an object is detected, the sensor receives the reflected sound waves, and based on the intensity or time delay of the received signal, it can determine if an object is present or not.

    3. Range and Accuracy: Ultrasonic sensors can have varying range capabilities, typically ranging from a few centimeters to several meters. The accuracy of distance measurement depends on factors such as the sensor's resolution, beam angle, and environmental conditions.

    4. Ultrasonic Transducer: The core component of an ultrasonic sensor is the transducer, which converts electrical energy into ultrasonic sound waves and vice versa. It consists of a piezoelectric crystal that vibrates when an electrical current is applied, generating the ultrasonic waves.

    5. Beam Pattern: Ultrasonic sensors emit sound waves in a specific beam pattern, usually conical or cylindrical. The beam angle determines the width of the detection area. Narrower beam angles provide more focused sensing, while wider angles cover a larger area but with reduced accuracy.

    6. Environmental Considerations: Ultrasonic sensors are affected by environmental factors such as temperature, humidity, and air turbulence. These factors can influence the speed of sound and affect the accuracy of distance measurements.

    7. Applications: Ultrasonic sensors are widely used in various fields, including industrial automation, robotics, automotive, security systems, level monitoring, parking assistance, liquid flow measurement, and presence detection in consumer electronics. 

The 10 Sensor were mounted as the following:
 - `L1` Sensor Left Front (Closer to the frontend of the robot).
 - `L2` Sensor Left Back (Closer to the backend of the robot).
 - `R1` Sensor Right Front (Closer to the Frontend of the robot).
 - `R2` Sensor Right Back (Closer to the backend of the robot).
 - `F` Sensor Frontal Sensor (In the middle of the frontend of the -obot).
 - `B` Sensor Rear Sensor (In the middle of the backend of the robot).
 - `BL` Sensor Back Left Sensor - mounted on the edge of the vehicle and tilted by 45 counterclockwise degrees about the x-axis of the robot.
 - `BR` Sensor Back Right Sensor - mounted on the edge of the vehicle and tilted by 45 clockwise degrees about the x-axis of the robot.
 - `FL` Sensor Front Left Sensor - mounted on the edge of the vehicle and tilted by -45 counterclockwise degrees about the x-axis of the robot.
 - `FR` Sensor Front Right Sensor - mounted on the edge of the vehicle and tilted by -45 clockwise degrees about the x-axis of the robot.

     ![ultrasonic sensor](/Documentation/Images/PowerAndSense/HC-SR04.jpg)
  <p Style="font-size:12px; color:grey; font-type:italic;"><i> Figure 37: Ultra Sonic Sensor - HC-SR04</i></p>

### Electrical Components Current Needs And Overall Circuit Usage

Accurate knowledge of the electrical component requirements is a crucial factor to be considered. Both theoritical and experimental information should be gathered to investigate the properties of the electrical circuit, this can be reduced to the following reasons:

- Optimal Power Supply Design:
Understanding the current needs of the robot's electrical components allows for the design of an appropriate power supply system, this helps in selecting a power source that can provide the required currents at the correct voltage levels so that the system's stability and performance can be ensured.

- Battery Life Optimization:
Since Lipo Batteries were used in the robot, knowing the current needs of the components is crucial for optimizing battery life.In results, Estimating accurately the current draw during different operational states, power-saving strategies can be implemented, such as allocating convenient batteries to the needed components. Additionally, this extends the robot's operating time and reduces the frequency of battery replacements or recharging.

- Heat Dissipation and Cooling:
Some electrical components may suffer from overheating due to its continous high current draw, so accurate knowledge of the overall circuit consumption aids in determining the heat generated by the components, which in sequence helps in implementing effective cooling mechanisms to prevent overheating, which can lead to performance degradation or even component failure. For example, we noticed that Raspberry Pi heat's increases noticably after long time of working, so we added a cooling fan in addition to heat sink wich helped avoiding overheating problem.

- Safety Considerations:
Understanding the overall circuit consumption is surely essential from a safety standpoint. By ensuring that the power supply system can handle the maximum expected current draw, the risk of electrical failures, such as voltage drops or circuit damage, can be mitigated, which also prevents potential hazards to both the robot and its environment.

- Cost Optimization:
When the electrical needs are known for each component, costs can be reduced without compromising performance or reliability by selecting components that meet the necessary specifications.

The properties of the robot's circuit can be understood in the table and figure below:

UltraSonic Sensor: The input current for an Ultrasonic Sensor can vary depending on the specific model and operating conditions. 
Typically, it ranges from a few milliamperes (mA) to around 15 mA. For more information check [here](https://www.google.com/url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)

MPU6050 Gyroscope Sensor: The input current for an MPU6050 Gyroscope Sensor is about 36 mA. For more information check [here](https://invensense.tdk.com/wp-content/uploads/2015/02/MPU-6000-Datasheet1.pdf)

Raspberry Pi Model B 4: The input current for a Raspberry Pi Model B 4 can vary depending on the connected peripherals and the workload. Typically, it requires around 2.5 A, but it is recommended in our case to use a power supply capable of providing 3A for stable operation. For more information check
[here](https://www.raspberrypi.com/products/raspberry-pi-4-model-b/specifications/).

Arduino Mega: The input current for an Arduino Mega board is typically around 50mA when idle. However, the current consumption can increase when using additional peripherals or when running more complex programs as the case in our robot.
For more information check [here](https://www.mantech.co.za/datasheets/products/A000047.pdf) and [here](https://store.arduino.cc/products/arduino-mega-2560-rev3).

Servo Motor SG Tower Pro: The input current for a Servo Motor can vary depending on the load and the specific model. Typically, it ranges from  0.5A – 2A, depending on the torque and speed requirements.
For more information check  [here](https://www.towerpro.com.tw/product/sg90-7/#:~:text=The%20operation%20current%20for%20our,4.8V%20–%206V%20are%20fine.)

Raspberry pi camera: The input current for a Raspberry Pi Camera Module can vary depending on the model and the camera settings. Typically, it requires around 250-300mA.

BTS7960 Motor Driver: The input current for a BTS7960 Motor Driver depends on the motor being driven and the load conditions. It can range from a few milliamperes (mA) to several amperes (A), depending on JSumo motor's state.

| Component                  | Input Current (mA) |
|----------------------------|-------------------|
| Ultrasonic Sensor         | 15             |
| MPU6050 Gyroscope         | 3.6            |
| Raspberry Pi Model B 4    | 3000                 |
| Arduino Mega              | 500                |
| Servo Motor SG Tower Pro  | 500-2000               |
| Raspberry pi camera  | 250 - 300               |

### Circuit ground

A common ground in a circuit is essential for maintaining accurate voltage measurements, ensuring reliable signal transmission, and mitigating signal noise and interference. It provides a consistent voltage reference for all components, simplifies circuit design and troubleshooting, and aids in maintaining signal integrity throughout the circuit. By establishing a shared reference point, the common ground enables effective communication between components and promotes optimal circuit operation.

----

## Obstacle Management 

Obstacle management is a crucial challenge that should be driven by robust algorithms, which offers precision without the loss of the speed. We developed our algoritms based on the previous requirements, and thus achieved noticeably reliable performance.  

### Computer Vision 

The integration of computer vision in latest techniques is considered an essential technology in robotics and automation. This can be seen especially in self-driving cars, where enabling the vehicle to see is essential, which means that it can perceive and understand the environment. By employing CV (computer vision) techniques, the robot in our task can gather valuable information from its surrounding, make informed decisions, and perform the required tasks. In this context, the isolation of red and green pillars is critical to prevent collisions and ensure the robot's path remains obstacle-free. However, since the computer vision function is only identifying red and green pillars of same size, the complexity can be reduced to color detection problem without the need for object detection. After determining the required CV algorithm, among the various color detection approaches available, such as HSL (Hue, Saturation, Lightness), HSB (Hue, Saturation, Brightness), RGB (Red, Green, Blue), and HSV (Hue, Saturation, Value), we have chosen to utilize the HSV color space, because in comparison to these color spaces:

- The HSV color space offers distinct advantages over other color spaces for our specific requirements. HSV separates color information from both brightness and saturation. This separation allows for better adaptation to different lighting conditions, making the HSV color space more robust and reliable for color detection tasks.
- While RGB is widely used and suitable for many applications, it presents challenges in color-based segmentation and sensitivity to lighting variations. The complex color manipulation in RGB makes it less suitable for our specific needs. On the other hand, the HSV color space simplifies the extraction and separation of specific colors from images, making it ideal for efficient color-based segmentation.

While the RGB color space is widely used and suitable for many applications, it was deemed less suitable for the specific requirements of image processing and color detection. RGB's complex color manipulation, challenges in color-based segmentation, and sensitivity to lighting variations were the primary factors that influenced our decision to opt for the HSV color space.

#### Pre-Processing: 

Before isolating the pillars to extract information, it was necessary to apply pre-processing on the captured images to improve the overall effectiveness of subsequent isolation. Preprocessing helps to eliminate unwanted artifacts and enhance relevant image features leading to more accurate and reliable segmentation results. It allows to prepare the image data in a way that maximizes the CV algorithm's performance, ensuring robust color detection and accurate boundary delineation. Our pre-processing operations contained applying a linear transformation to the pixel intensity values of the images. We used alpha and beta parameters, the alpha parameter controls the contrast adjustment, determining how much the pixel values are scaled. A larger alpha value increases the contrast, making the dark regions darker and the bright regions brighter. Additionally, the beta parameter represents the brightness adjustment, determining the amount of brightness added to the image. By adjusting these parameters, they can be used to modify the image's appearance, enhancing or reducing the contrast and brightness levels. Moreover, we applied Gaussian filtering. By averaging the pixel values in the neighborhood, with more emphasis on the nearby pixels according to their proximity to the center. it effectively reduced high-frequency noise and smoothed out details. We also applied erosion to shrink the boundaries of objects in an image in order to remove small details and smoothen the image. Finally, Dilatation was applied to expand the boundaries of objects to enhance the size and shape of objects.
 
![Pre-Processing flow chart](/Documentation/Images/ComputerVision/CV2.png)
<p align="center" Style="font-size:12px; color:grey; font-type:italic;"><i> Figure 38:Pre-Processing flow flowchart </i></p>

#### Masks:

To isolate the color of green and red pillars we applied three masks on the pre-processed image. These masks black out all pixels that are not in the range of the specified HSV values. HSV masks are binary images that are used to isolate specific colors or ranges of colors in an image based on the HSV color space. These masks are created by setting pixels within the desired color range to white (255) and pixels outside the range to black (0). HSV masks are commonly used in various computer vision applications, such as color-based object detection, image segmentation, and tracking. The steps of making the masks are:
1. Convert the input image from the RGB color space to the HSV color space.
1. Define the lower and upper thresholds for the desired color range in terms of hue, saturation, and value values.
1. Iterate through each pixel in the HSV image and check if it falls within the specified color range.
1. For pixels within the range, set the corresponding pixel in the mask image to white (255); otherwise, set it to black (0).
1. The resulting mask image will have white pixels representing the desired color range and black pixels representing all other colors.

HSV values in our work were as follows: (([0,100,50] to [0,255,255] and [163,100,54] to [179,255,255] for red due to the cylindrical shape of the hue values) – (([43, 50, 45] to [43, 50, 45] for green)). 

#### Image Thresholding:
Thresholding is a technique used to convert a grayscale or single-channel image into a binary image, where pixel values are classified into two categories based on a specified threshold value.
The general syntax for using OpenCV library thresholding:

*ret, threshold = cv2.threshold(src, thresh, maxval, type)**
* src: The source image, which should be a single-channel (grayscale) image.
* thresh: The threshold value used for classifying pixel values.
* maxval: The maximum value assigned to pixels that exceed the threshold.
* type: The thresholding type, which determines the specific algorithm used for thresholding. 

Common types include cv2.THRESH_BINARY, cv2.THRESH_BINARY_INV, cv2.THRESH_TRUNC, cv2.THRESH_TOZERO, and cv2.THRESH_TOZERO_INV.

Return values:
1. ret: The threshold value that was used (sometimes automatically calculated).
2. threshold: The resulting binary image after applying the thresholding operation.

The cv2.threshold function compares each pixel value in the source image with the threshold value. Pixels with values greater than the threshold are assigned the maxval value, while pixels with values below the threshold are set to 0 or a lower value (depending on the thresholding type).
#### Contouring:

Contouring in OpenCV and computer vision refers to the process of detecting and representing the boundaries of objects or shapes in an image. Contours are widely used in computer vision for various tasks, such as object detection, shape analysis, motion tracking, and image segmentation.

#### What pillar is the closest pillar to the vehicle?
The decision of what pillar is closest  to the vehicle is made by many selection processes as following and for each contour in the image:
1. Finding the moments (specifically the centroid) of the contour.
2. Finding the bounding rectangle about the contour.
3. Calculating the area of the contour using cv2.contourArea function.
4. Calculating the mean area of the two previous contours(Since the first contour is a rectangle, it may not give an accurate area with some orientations of the camera. Additionally, the second contour may contain noise and not thus don’t give the correct area)
5. Taking the largest area contour as the selected one.
These steps are applied on the red and green masks.
It should be noted that the orientation of the used camera (Raspberry pi camera) maintain a range of view that allow to detect more than one pillar, more specifically, when the robot is in the corner section, the pillars in the end of the next section can be seen on the camera, but without objects from outside (We cropped the images to ensure that no outer objects are evident in the image).
 
 ![Area Calculation](/Documentation/Images/ComputerVision/CV1.png)<p align="center" Style="font-size:12px; color:grey; font-type:italic;"><i> Figure 39: Area calculation flowchart </i></p>

#### What is the distance between the pillar and the vehicle?
After finding the largest contour we can find the distance between the vehicle and the pillar using a mathematical expression found by a curve fitting model that was built on experimental data of the contour area and the actual distance. The data can be found in Appendix **:
 
 ![Area Calculation](http://www.sciweavers.org/tex2img.php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)

#### How is CV used in the robot?

Two algorithms were developed and tested for CV processing, One algorithm *"Persistent Vision"* operates continuously, processing incoming images in real-time and promptly relaying the results. The other algorithm "Event Driven Vision", on the other hand, remains dormant until it receives a start signal, and sends the results once only.

**1 - Persistent Vision**  

The Persistent Vision algorithm continuously processes camera input images and performs a series of pre-processing operations detailed in [Pre-Processing](#Pre-Processing). It utilizes the HSV color space to isolate colors and identifies the region of interest, which corresponds to the red and green pillars. Subsequently, it calculates the area of all contours present in the image and selects the closest one. Based on the measured distance,  the algorithm determines the state of the pillar. Once the colsest pillar to the vehicle is identified, the raspberry pi sends a signal composed of single character via serial connection to the microcontroller. This signal consists of one of the following letters that define the state of the pillar: "G," "R," "g," "r," or "N". These letters indicate the presence of: a close green pillar (distance < 50cm),  close red pillar (distance < 50cm), far green pillar (distance > 50cm), far red pillar (distance > 50cm), or no green or red pillar, respectively.

  ![Persistent Vision](/Documentation/Images/ComputerVision/PersistentVision.png)<p align="center" Style="font-size:12px; color:grey; font-type:italic;"><i> Figure 40:Persistent Vision algorithm flowchart </i></p>

**2 - Event Driven Vision** 

In the Event Driven Vision algorithm, processing occurs once a signal is received from the Arduino. The Arduino sends this signal at the beginning of each section, after the robot has stopped and assumed the correct position. The algorithm follows the same steps as before but with some modifications. It takes all pillars contours that are present in the scene (camera input images) and applies the following procedures. We will refer to the section the robot is entering as the "current section" and the following section as the "next section":

1- Count the number of pillars within the maximum range present in the image. Pillars located beyond the end of the current section are disregarded. This comes from the fact that they do not impact the robot's movement decision in the current section.

2- Once the number of pillars is determined, their information is stored in an array that includes the area, X and Y coordinates of the contour centroid, color, and distance for each contour.

3- There are three cases to consider:

- If there are three stored pillars, the array is sorted based on the area. This situation arises when there are two pillars in the current section and one pillar is present at the start of the next section. In a such case, the HSV color isolation may fail to ignore the farthest pillar, leading to inaccurate distance calculation and the inclusion of unwanted pillars. The contour centroids are used to identify the pillars within the borders of the current section. This is based on the understanding that when the moving direction (CW or CCW) is known, the x-coordinates of contours centroids can be used to determine which pillar is unwanted.
- If there are only two stored pillars, the array is sorted directly based on the centroids. The presence of a pillar at the beginning of the current section can be easily determined through distance, there are two subcases to consider. In the first subcase (Existence of a pillar at the start of the current section), the other pillar is taken into account. In the contrary subcase, where it is impossible for two pillars to exist in the same section when neither is at the beginning of the current section, only the closest pillar is considered.
- The simplest case involves the detection of only one pillar. In this scenario, the decision is made directly based on the color alone.

After finishing the processing, only one signal is sent to arduino and image capturing with processing will stop, it will wait until a signal from the arduino arrives again. The raspberry pi signal contains one of the strings (“R”,”G”,”GG”,”RR”,”RG”,”GR").

  ![Event Driven Vision](/Documentation/Images/ComputerVision/EventDrivenVision.png)<p align="center" Style="font-size:12px; color:grey; font-type:italic;"><i> Figure 41: Event Driven Vision algorithm flowchart </i></p>

Some cases are visually explained below:
 - In this case two green pillars are located in the current section, so they will be both considered:

   ![Event Driven Vision](/Documentation/Images/ComputerVision/Green_Green_case.jpg)<p align="center" Style="font-size:12px; color:grey; font-type:italic;"><i> Figure 42:Two green pillars case </i></p>

 - In this case two red pillars are located in the current section, so they will be both considered:

   ![Event Driven Vision](/Documentation/Images/ComputerVision/Red_Red_case.jpg)<p align="center" Style="font-size:12px; color:grey; font-type:italic;"><i> Figure 43:Two red pillars case </i></p>

 - In this case only one green pillar is located in the current section:

   ![Event Driven Vision](/Documentation/Images/ComputerVision/Green_case.jpg)<p align="center" Style="font-size:12px; color:grey; font-type:italic;"><i> Figure 44:One green pillar in the current section case </i></p>

 - In this case one green pillars is located in the current section, and the other is located in the next section, so only the first one will be considered:

   ![Event Driven Vision](/Documentation/Images/ComputerVision/Green_Ignore_Green_case.jpg)<p align="center" Style="font-size:12px; color:grey; font-type:italic;"><i> Figure 45:One green pillar in the current section and another in the next section case </i></p>

- In this case, a red pillar and a green pillar are present in the current section, and one green pillar is in the next section, which won't be considered:

   ![Event Driven Vision](/Documentation/Images/ComputerVision/Red_Green_case.jpg)<p align="center" Style="font-size:12px; color:grey; font-type:italic;"><i> Figure 46:Red and green in pillars in current section and green pillar in the next section case </i></p>

- In this case, a red pillar exist in the current section, and one green pillar is in the next section, which won't be considered:

   ![Event Driven Vision](/Documentation/Images/ComputerVision/Red_Ignore_Green_Case.jpg)<p align="center" Style="font-size:12px; color:grey; font-type:italic;"><i> Figure 47:Red pillar in the current section and green pillar in the next section case </i></p>

#### Open Challenge Algorithm 

In this challenge, the required task is completing three laps in the least possible time, this requires constructing an algorithm that guarantees precise navigation in addition to fast and smooth movement between the sections.
Our main idea is built upon partioning the section for two areas, this approach enables us to address and solve each problem independentatly. The first area, referred to "Protected Area", contains the majority of the robot's path inside of it (Green area) as illustrated in the figure below. The second area, which is  "Unprotected Area", is the unsafe area in which the robot becomes very close to the wall as illustrated in the figure below (Red area).

![Pre-Processing flow chart](/Documentation/Images/ObstacleManagement/Area.png)<p align="center" Style="font-size:12px; color:grey; font-type:italic;"><i> Figure 48:Protected and unprotected area illustration </i></p>

##### Moving in Protected Area

In the Protected area, the robot can move safely without the risk of hitting the wall, building upon this fact, it is enough for the robot to keep moving in a straight line and parallel to the wall (no high risk of hitting the wall). PD algorithm was used to keep the robot's angle constant, the algorithm takes the reading of the gyroscope as input, and setpoint is taken after the completion of the turn. Equation below represents the formula for calculating the error and the needed angle for the servo to turn: 

$PIDOutput = K_{p(protected)} \times Error_{t} + \frac{Error_{t} - Error_{t-1}}{IntervalLength} \times k_{d(Protected)}$

$Error_{t} = GyroscopeReading - SetPoint$

However, relying only on the gyroscope sensor arises inaccurate setpoint calculation sometimes. This can be seen after the completion of the robot's turn, the robot may not turn exact 90 degrees, it can be less or more. Therefore, a correction formula is utilized to correct gyroscope's reading and calculate the correct setpoint:

$Angle = tan^{-1}(\frac{D_{S1} - D_{S2}}{D_{S1S2}})$

![ِAngle Calculation](/Documentation/Images/ObstacleManagement/AngleCal.png) <p align="center" Style="font-size:12px; color:grey; font-type:italic;"><i> Figure 49: illustration of angle calculation</i></p>

Final output can be calculated using the formula below:

$ServoAngle = Angle + PIDOutput$

Where:

- $PIDOutput$ is the calculated servo angle using PD only.
- $SetPoint$ is the reference angle (in which the robot is parallel to the wall).
- $Error_{t}$ is the difference between the current reading and $SetPoint$ in time $t$.
- $K_{p}$ is the proportional gain.
- $K_{d}$ is the derivative gain.
- $IntervalLength$ is the time period to take one measurement.
- $D_{S1}$ is the front right/left sensor reading.
- $D_{S2}$ is the rear right/left sensor reading.
- $D_{S1S2}$ is the distance between the front right/left sensor and the rear right/left sensor.
- $Angle$ is the angle between the robot and the wall.
- $ServoAngle$ is the final servo angle.

##### Moving in Unprotected Area

When entering the unprotected area, the movement is unsafe inside this area. The robot will have to immediately move away from the unprotected area until it reaches the protected area. We used P controller with a relatively high proportional gain:

$ServoAngle = K_{p(unprotected)} \times (D_{vertical} - D_{unprotected})$

$D_{vertical} = cos(Angle) \times \frac{D_{S1}+D_{S2}}{S2}$ 

where:

- $ServoAngle$ is the turning angle of servo motor.
- $K_{p(unprotected)}$ is the proportional gain in unprotected area.
- $D_{vertical}$ is the vertical distance between the robot and the wall.
- $D_{unprotected}$ is the unprotected area width.

The vertical distance was chosen to inlcude in the formula because it measures the accurate position of the robot relative to the wall, this yield more accureate results compared to the measured distance alone by one sensor or the average of the two. The distance can be calculated using simple geometry.

##### Detecting turns and direction

Once the robot detects a significant distance (>100cm), The robot identifies a turn. However, the robot can be not parallel to the wall in a way that results in wrong ultrasonic readings, as a consequence of the small this rein this case, the robot detects the front wall using front ultrasonic sensor, in case it is impossible to turn safely, the robot move backward until it reaches a point where the turn is safe.
The robot will determine the direction of movement (CW/CCW) in the first turn, this can be done by determining on which side of the robot the turn was detected. 

#### Obstacle Challenge Algorithm  

We mentioned previously that we have developed two algorithms, one that continuously process the scene and send information "Persistent Vision", and one that work only when it receives a signal from the arduino to start processing and send the information once "Event Driven Vision".
Based on the chosen algorithm, the robot follows a unique way to manage its movement and avoid red and green obstacles, we'll first discuss the general approach and mathematical formulas that drives the robot movements when avoiding the obstacles, then we'll discuss in depth each algorithm separately.

##### General Approach and Mathematical Formulas  

This section presents the general approach and mathematical formulas utilized in the algorithm design for the robot's movement and obstacle avoidance. 
The primary objective of our approach is to ensure the robot moves in a manner that guarantees a safe path without collisions. 
So During the algorithm's design stage, our main motivations were focused on achieving robustness, adaptability, and fault tolerance.

##### 1 - Robustness and Adaptability

 - The algorithm is designed to function effectively regardless of the robot's relative position to obstacles.
 - It takes into account various scenarios where the robot may be situated in proximity to obstacles from different angles or distances.
 - By considering relative position independence, the algorithm ensures consistent obstacle avoidance irrespective of the robot's location.

##### 2 - Fault Tolerance

 - It is essential to address possible faults in the robot's movements that can affect the obstacle avoidance and ensure uninterrupted obstacle avoidance.

Those considerations led us to a mathematical formula, that calculates the needed angle to turn, we considered three cases:

##### 1- Normal Case
 
- The robot receives a signal from Raspberry Pi indicating that the robot should turn to avoid the pillar, the robot will calculate the desired angle using the formula:

  ![Persistent Vision](/Documentation/Images/ObstacleManagement/DesiredAngleFormula.png)

 - D<sub>obstacle</sub>
  is the distance between the robot and the obstacle.
 - D<sub>wall</sub>
  is the distance between the robot and the wall.
 - DesiredAngle is the angle that the robot should turn to avoid colliding with the wall.
  ![Avoid](/Documentation/Images/ObstacleManagement/avoid.png)
 <p align="center" Style="font-size:12px; color:grey; font-type:italic;"><i> Figure 50: illustration of Desired angle calculation </i></p>

##### 2- Safe Case

- The robot receives a signal from Raspberry Pi indicating that the robot should turn to avoid the pillar, the robot will calculate the desired angle using previous formula, if it is less than 11° degrees, this indicates that the robot is within the limits of the safe range (where it can continue its movement in a straight line without the need to turn), it sets the angle to zero, which means that the robot won't turn.

##### 3- Extreme Angle Case

 - The robot receives a signal from Raspberry Pi indicating that the robot should turn to avoid the pillar, the robot will also calculate the desired angle using previous formula, if it is higher than a certain value 64° degrees, this indicates that the robot is dangerously far from the wall in a way that makes it have to turn a big angle. We set an upper limit to fix this angle, this ensures that the robot will turn safely.

After achieving the desired angle, the robot will move straight along the angle that was turned, using a PD controller to maintain a steady path until it reaches a specified distance from the wall. This distance is not the vertical distance from the wall:

 1- If the robot heading towards the outer wall, it will keep moving until the front radical sensor, which is on the wall side, read lower than a specified distance.
  
 2- If the robot heading towards the inner wall, it will keep moving until the back radical sensor, which is on the outer wall side, read higher than a specified distance.

The Arduino will send signal to the servo motor to turn the same angle, but this time in the opposite direction using Gyroscope sensor.
In both Normal case and Extreme Angle case, the used formula considers that the robot's angle is 90 degrees. However, some errors can happen that may lead to more or less than 90 degrees, we use the formula below to calculate this angle simple geometry and correct the desired angle:

  ![Persistent Vision](/Documentation/Images/ObstacleManagement/AngleCorrection.png)

It should be noted that both equations yield results in Radian, so a conversion formula is used to convert the angles to degrees:

  ![Persistent Vision](/Documentation/Images/ObstacleManagement/Conversion.png)

#### Navigation Methods

The process of robot’s navigation at Straight-Froward sections controls the movements of robot after passing the pillar until it reaches a corner section. We divide these movements into three main methods:

- Follow-Right (for avoiding red pillar)
- Follow-Left (for avoiding green pillar)
- Follow-Middle only when robot detects no traffic sign (it is applicable for first section).

for every method we focused on the development of robust navigation methods to ensure safe and stable following of a robot. A fundamental requirement is the implementation of a reliable following algorithm capable of maintaining these essential criteria. While the Proportional-Derivative (PD) following algorithm effectively ensures a safe path, it keeps the robot at a calibrated setpoint (constant path) parallel to the wall, exploiting its dynamic capabilities. 
The PD algorithm enables the vehicle to maintain a zero degrees angle, thereby keeping the robot moving in a straight trajectory. The angle calculation is derived from a specified formula based on ultrasonic readings. 
Nonetheless, scenarios may arise where the robot approaches the wall in a hazardous manner, necessitating a prompt response. To handle such situations effectively,
we devided the area within the straight forward section into two distinct regions: a protected area and an unprotected area. In the protected area, the robot utilizes the PD controller to follow the specified angle. Conversely, the unprotected area mandates the robot to execute abrupt turns, facilitating a swift exit from the dangerous zone and subsequent return to the protected area for continued PD following.

#### AVOID PILLARS (GENERAL)
These steps outline the process for navigating a vehicle using a gyroscope and radical sensors.
The navigation will be divided into three distinct phases:

- Phase 1: Turn a Fixed Angle using the Gyroscope

  i. The navigation process starts by receiving an ”R” or ”G” signal to the Raspberry Pi.

  ii. Use the gyroscope to turn a fixed angle in either a clockwise (CW) or counterclockwise
  (CCW) direction, depending on the scenario.

- Phase 2: Move Straight using the PD Controller

  i. Move straight along the angle that was turned, using a PD controlling to maintain a
  steady path.

  ii. Continue moving straight until the radical sensor reads a close distance. Depending on
  the situation, either the front or back radical sensor will be utilized.

- Phase 3: Turn in the Opposite Direction and Continue

  i. Turn the same angle as in phase 1, but in the opposite direction.

  ii. Continue following either the right or left path, based on the particular scenario.

#### Movement In Corner Section 

These steps outline the process for navigating a vehicle in corner sections through three distinct scenarios. The following steps are considered for a counterclockwise (CCW) direction. For (CW) steps for scenarios 2 and 3 will be reversed.

##### Scenario 1: Entering the Corner from Follow-Middle

- Phase 1: Move in Follow-Middle

  i. Continue moving in Follow-Middle within the corner section until the front sensor reads lower than 30cm.

- Phase 2: Turn Backward and Calibrate

  i. Turn backward for 90 degrees CCW to face the following straight forward section, using the gyroscope.

  ii. The turn-back move is calibrated to be finished in the middle of the corner (close to the outer border and not too far from it).

- Phase 3: Move Backward and Turn

  i. Move backward (angle-Right) until the back sensor reads lower than 10cm.

  ii. Move to the following straight forward section in the middle.

##### Scenario 2: Entering the Corner from Follow-Right

- Phase 1: Move in Follow-Right

  i. Continue moving in Follow-Right within the corner section until the front sensor reads lower than 50cm.

- Phase 2: Turn Forward

  i. Turn for 90 degrees CCW to face the following straight forward section, using the gyroscope.

- Phase 3: Move to the Following Straight Forward Section

  i. Move to the following straight forward section in the middle.

##### Scenario 3: Entering the Corner from Follow-Left

- Phase 1: Move in Follow-Right

  i. Turn forward for 30 degrees CW, using the gyroscope.

- Phase 2: Move Straight

  i. Move straight following the same angle you have turned until the radical sensor reads lower than 50cm.

- Phase 3: Turn and Repeat
i. Turn the angle in phase 1 in the opposite direction.

  ii. Repeat phases 1, 2, and 3 of scenario 1 to continue through the corner section.

#### Obstacle Management With Persistent Vision 

These Scenarios outline the process for navigating a vehicle through three distinct scenarios using
a gyroscope and radical sensors, and detecting pillars using serial communication and image
processing:

- Phase 1: 2 pillars in the section or one pillar in the beginning of the section

  i. . If a big letter ”R” or ”G” is received, check if there is a close pillar using the back
  sensor (lower than 70cm).

  ii. If the R or G signal is sent from the Raspberry Pi for a pillar closer than 50cm, that
  means the pillar is in the beginning of the section.

  iii. Repeat phases 1 and 2 of the Avoiding Pillars navigation, but make sure to use the
  Radical Back sensors when needed.

  iv. When phase 2 is completed, turn slightly inward to the straight forward section to check
  for another pillar.

  v. If there is no pillar or a pillar of the same color, continue following either the right or left
  path.

  vi. If there is a pillar of a different color, repeat phases 1, 2, and 3 of the Avoiding Pillars
  navigation.

- Phase 2: 1 pillar in the section in the middle or the end of the section
  The checking process in the first scenario gives information about where the only pillar
  is located and if the pillar is located in the middle or the end of the section the robot will
  continue following straight until it gets “R” or “G’ from the raspberry pi, and then it bypasses
  the pillar using general steps until it gets to the corner section.

#### Obstacle Management With Event Driven Vision 

This algorithm can be divided into three steps:

  When the robot is in the proper place at start of cornern section,
   and facing the next straight forward section. The controller (Atmega) will send a signal containing either letters
 "L" or "R", which indicates the direction of the vehicle (CW or CCW). Eventually, the processor recieves the signal and starts 
 to take a capture for the faced straight forward section and identify the number of pillars in this section and their colors.
  Then it sends a signal to the controller taking the different possible cases. The vehicle deals with these cases as mentioned 
  in [General Approach and Mathematical Formulas pillars cases](#subtitle1) based on previously established color information without looking for a second pillar in the section .
**Computer vision referral**

#### Comparasion Between Persistent Vision and Event Driven Vision algorithms 

| Algorithm | Event Driven Vision | Persistent Vision |
|-----------|:------------------:|:----------------:|
| Approach  | - Waits for a signal indicating the robot is in the first section and stops. <br>- Processes the scene using the camera only once and sends information as a signal to the Arduino controller. <br>- Robot knows exactly what to do in the current section. | - Processes the scene continuously without stopping until the three laps are completed. <br>- Constantly analyzes the image to detect and react to obstacles in real-time. <br>- After avoiding a pillar, the robot turns a small angle to check for the existence of another pillar.|
| Advantages | - Provides precise information about the current section, enabling accurate decision-making. <br>- Robot knows exactly what actions to take based on the processed image. | - Real-time processing allows the robot to react swiftly to obstacles. <br>- Continuous processing minimizes the risk of missing or misclassifying pillars. <br>- Less reliant on accurate long-distance recognition of red and green pillars. |
| Disadvantages | - Relies on a signal to indicate the start of each section, which would suffer from delays or synchronization issues. <br>- May struggle with red or green pillars isolating and distance calculation from a distance, which may lead to incorrect actions. | - Lacks prior knowledge of the current section, requiring continuous processing and decision-making. <br>- Requires the robot to turn and check for the presence of pillars, potentially affecting efficiency and speed. |
| Suitability | - Suitable when accurate knowledge of each section is crucial for decision-making. <br>- May be suitable for scenarios where pillars are reliably detectable from a close distance. | - Suitable for real-time obstacle detection and avoidance. <br>- Can handle scenarios where long-distance recognition of pillars is challenging or unreliable. |

#### Efficient Play-field Pillar Data Storage
When the play-field randomization has been completed, and the pillar colors and their positions within the play-field remain constant over the course of three laps, it becomes advantageous to retain the data regarding the play-field's pillar locations and colors. The optimal approach is for the robot to capture this information during the first lap and subsequently suspend image processing, relying solely on the stored data for subsequent laps.
As our algorithm is designed to account for the positions of these pillars, it is worthwhile to store this information in a List. Each element in the list should contain comprehensive information about a particular section, as explained in detail within the code.

#### Last Lap
 
The determination of the final turn direction hinges on the color of the pillar encountered during the last lap, specifically in the second-to-last lap. Two scenarios arise: if the pillar's color is green, the robot should continue the final turn in the same direction. Conversely, when the pillar is red, the robot is required to execute a reversal of the previous turn. The process of reversing the direction is undertaken within the corner section and is detailed as follows:

To transition from a counterclockwise (CCW) to a clockwise (CW) direction, the following steps are followed:

- Continue moving until the front distance sensor registers a distance of less than 75cm.

- Execute a 90-degree turn in the CCW direction.

- Move in reverse until the rear distance sensor indicates a distance less than 45cm.

- Move forward in the CCW direction until the robot reaches an angle of 30 degrees.

- Turn 80 degrees and proceed in reverse in the CCW direction.

- Continue moving in reverse until the rear distance sensor detects a distance less than 10cm.

---
### Conclusion
In conclusion, the autonomous vehicle we created for successfully solved the problems proposed in the WRO 2023 Future Engineers Category (Open Challenge - Obstacle Challenge) with the integration of mechanical and mathematical engineering principles, programming, and computer vision.  The advanced programming, real-time decision-making and computer vision algorithms enabled the vehicle to plan paths and make informed choices leading to a vehicle can navigate autonomously, aligning with the goal of connecting the world. Finally, the algorithm can improved to solve the tasks in shorter time and this project paves the way for further advancements and underscores the potential for a more connected world through innovative engineering solutions.

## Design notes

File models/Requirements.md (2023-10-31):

The chassis design with the extension .io can be opened using the stud.io program. The part designs as well as the assembly of the (coupler, side and seiling cover)  designs can be opened using CATIA V5 program and SolidWorks.

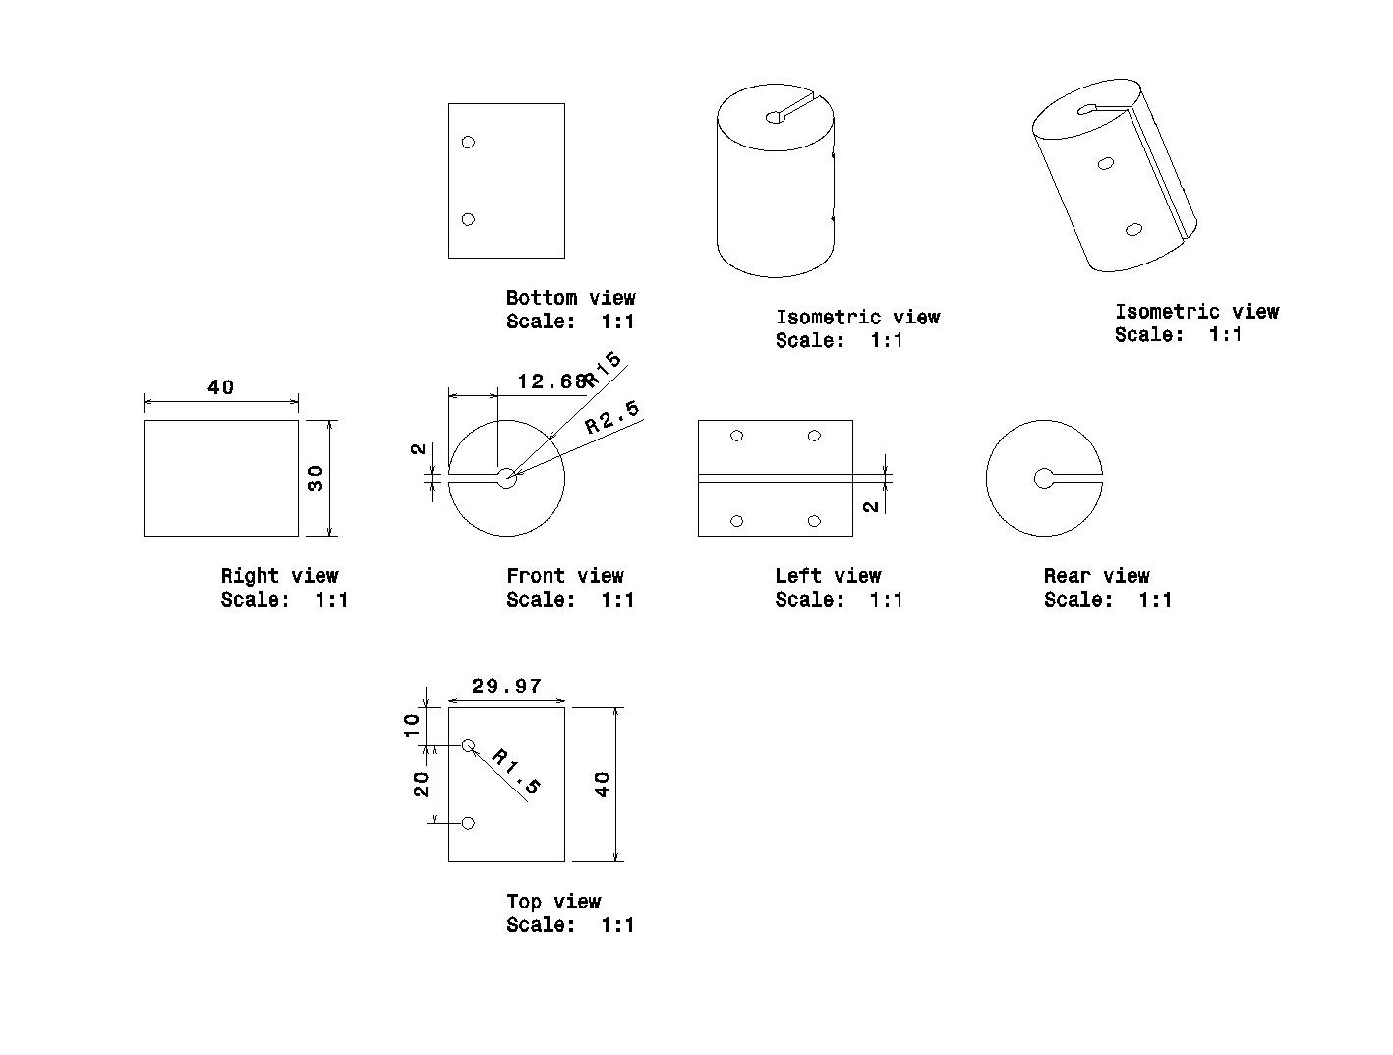
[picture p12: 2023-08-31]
models/Coupler Designs/Coupler.jpg

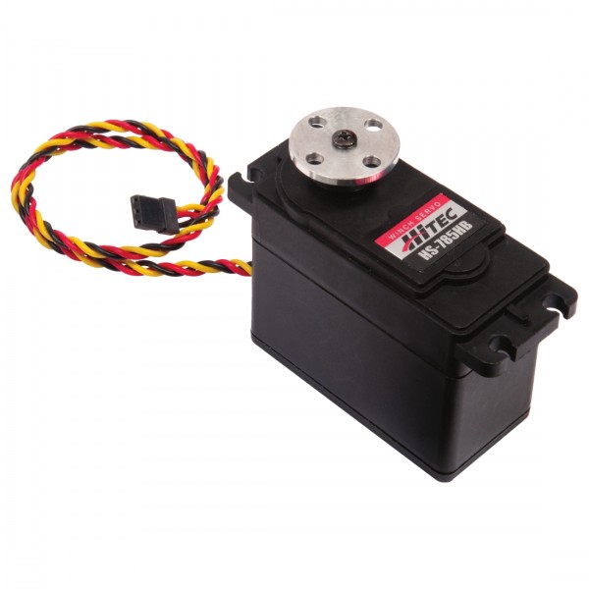
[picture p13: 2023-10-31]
Documentation/Images/PowerAndSense/HS-785HB.jpg

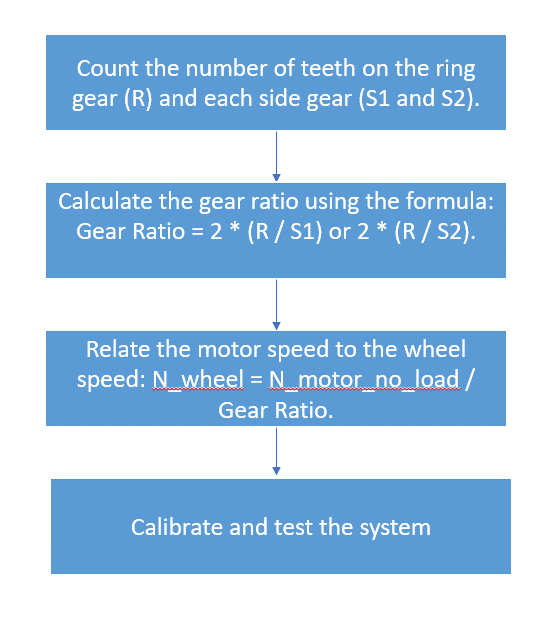
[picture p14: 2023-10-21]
Documentation/Images/Steering+Mechanism/Picture3.png

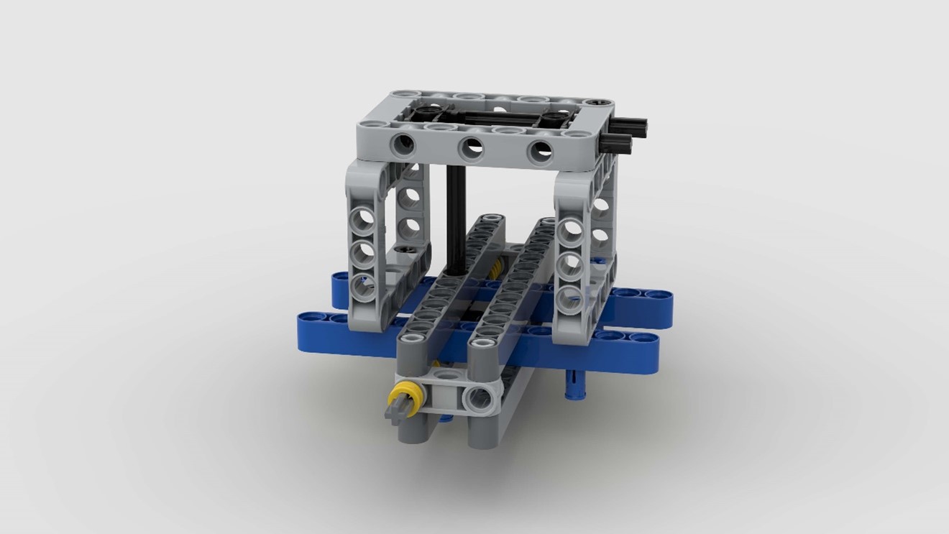
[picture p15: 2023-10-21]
Documentation/Images/Steering+Mechanism/Picture1.jpg

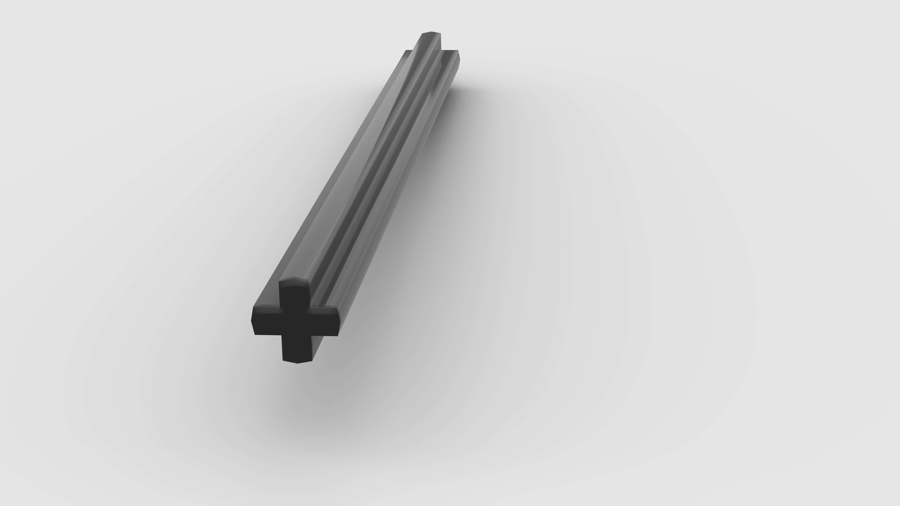
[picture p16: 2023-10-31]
Documentation/Images/Steering+Mechanism/Servo.jpg

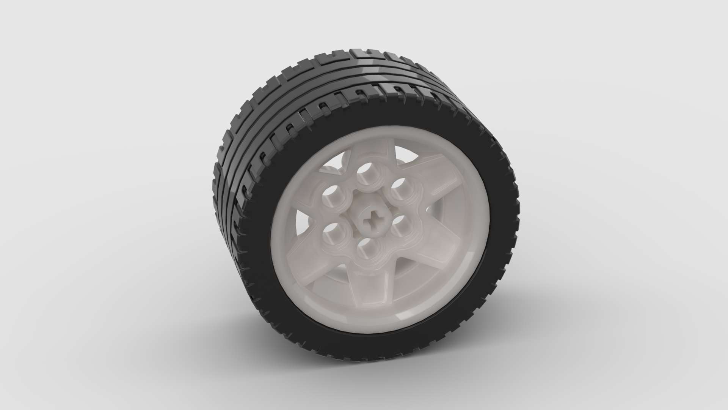
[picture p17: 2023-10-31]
Documentation/Images/Steering+Mechanism/Wheel.jpg

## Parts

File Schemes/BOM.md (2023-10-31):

<body>
<h1>Bill of Materials: Autonomous Buggies's Vehicle</h1>

<h2>Assembly List</h2>
<table>

  <thead>
   <tr>
    <th>Label</th>
    <th>Part Type</th>
    <th>Properties</th>
    </tr>
  </thead>
  <tbody>
  <tr>
    <td>BAT1</td>
    <td>12 battery</td>
    <td class="props">package battery ; Li-Po Battery</td>
</tr><tr>
    <td>BAT2</td>
    <td>12 battery</td>
    <td class="props">package battery ; Li-Po Battery</td>
</tr><tr>
    <td>GY2</td>
    <td>MPU-6050 Board GY-521</td>
    <td class="props">row double; package THT; form ♀ (female); hole size 1.0mm,0.508mm; pin spacing 0.1in (2.54mm); variant variant 1; pins 8</td>
</tr><tr>
    <td>J1</td>
    <td>Basic Servo Motor</td>
    <td class="props"> SG-Tower pro</td>
</tr><tr>
    <td>LM1</td>
    <td>RioRand LM2596</td>
    <td class="props">DC-DC Converter - 2A</td>
</tr><tr>
    <td>LM2</td>
    <td>RioRand LM2596</td>
    <td class="props">DC-DC Converter - 2A</td>
</tr><tr>
    <td>LM4</td>
    <td>RioRand LM2596</td>
    <td class="props">DC-DC Converter - 5A</td>
</tr><tr>
    <td>M1</td>
    <td>BTS7960</td>
    <td class="props">editable pin labels false; variant BTS7960; pins 12</td>
</tr><tr>
    <td>M2</td>
    <td>DC Motor</td>
    <td class="props">Jsumo Motor</td>
</tr><tr>
    <td>Mod1</td>
    <td>HC-SR04 Ultrasonic Distance Sensor</td>
    <td class="props">chip LM324</td>
</tr><tr>
    <td>Mod2</td>
    <td>HC-SR04 Ultrasonic Distance Sensor</td>
    <td class="props">chip LM324</td>
</tr><tr>
    <td>Mod3</td>
    <td>HC-SR04 Ultrasonic Distance Sensor</td>
    <td class="props">chip LM324</td>
</tr><tr>
    <td>Mod4</td>
    <td>HC-SR04 Ultrasonic Distance Sensor</td>
    <td class="props">chip LM324</td>
</tr><tr>
    <td>Mod5</td>
    <td>HC-SR04 Ultrasonic Distance Sensor</td>
    <td class="props">chip LM324</td>
</tr><tr>
    <td>Mod6</td>
    <td>HC-SR04 Ultrasonic Distance Sensor</td>
    <td class="props">chip LM324</td>
</tr><tr>
    <td>Mod7</td>
    <td>HC-SR04 Ultrasonic Distance Sensor</td>
    <td class="props">chip LM324</td>
</tr><tr>
    <td>Mod8</td>
    <td>HC-SR04 Ultrasonic Distance Sensor</td>
    <td class="props">chip LM324</td>
</tr><tr>
    <td>Mod9</td>
    <td>HC-SR04 Ultrasonic Distance Sensor</td>
    <td class="props">chip LM324</td>
</tr><tr>
    <td>Mod10</td>
    <td>HC-SR04 Ultrasonic Distance Sensor</td>
    <td class="props">chip LM324</td>
</tr><tr>
    <td>Part1</td>
    <td>Arduino Mega 2560 (Rev3)</td>
    <td class="props">type Arduino MEGA 2560 (Rev3)</td>
</tr><tr>
    <td>Raspberry pi 4 model b</td>
    <td>Raspberry pi 4 model b</td>
    <td class="props"></td>
</tr><tr>
    <td>Raspberry pi camera v.2</td>
    <td>Raspberry pi camera v.2</td>
    <td class="props"></td>
</tr><tr>
    <td>U1</td>
    <td>SWITCH-SPST-2</td>
    <td class="props">package r_sw_th; variant ra</td>
</tr>
  </tbody>
</table>
<h2>Shopping List</h2>
<table>
  <thead>
	<tr>
    <th>Amount</th>
    <th>Part Type</th>
    <th>Properties</th>
    </tr>
  </thead>
  <tbody>
<tr>
    <td>2</td>
    <td>12 battery</td>
    <td class="props">package battery ;  Li-Po Battery</td>
</tr><tr>
    <td>1</td>
    <td>MPU-6050 Board GY-521</td>
    <td class="props">row double; package THT; form ♀ (female); hole size 1.0mm,0.508mm; pin spacing 0.1in (2.54mm); variant variant 1; pins 8</td>
</tr><tr>
    <td>1</td>
     <td>Basic Servo Motor</td>
    <td class="props"> SG-Tower pro</td>
</tr><tr>
    <td>2</td>
    <td>RioRand LM2596</td>
    <td class="props">DC-DC Converter - 2A</td>

</tr><tr>
    <td>1</td>
    <td>RioRand LM2596</td>
    <td class="props">DC-DC Converter - 5A</td>
    <tr>
    <td>1</td>
    <td>BTS7960</td>
    <td class="props">pins 12</td>
</tr><tr>
    <td>1</td>
   <td>DC Motor</td>
    <td class="props">Jsumo Motor</td>
</tr><tr>
    <td>10</td>
    <td>HC-SR04 Ultrasonic Distance Sensor</td>
    <td class="props">chip LM324</td>
</tr><tr>
    <td>1</td>
    <td>Arduino Mega 2560 (Rev3)</td>
    <td class="props">type Arduino MEGA 2560 (Rev3)</td>
</tr><tr>
    <td>1</td>
    <td>Raspberry pi 4 model b</td>
    <td class="props"></td>
</tr><tr>
    <td>1</td>
    <td>Raspberry pi camera v.2</td>
    <td class="props"></td>
</tr><tr>
    <td>1</td>
    <td>SWITCH-SPST-2</td>
    <td class="props">package r_sw_th; variant ra</td>
</tr>
  </tbody>
</table>
</body>
</html>

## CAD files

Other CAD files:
models/Coupler Designs/Coupler.CATPart
models/Vehicle Cover/Assembly Side+Ceiling Cover.CATProduct
models/Vehicle Cover/cieling.CATPart
models/Vehicle Cover/side.CATPart

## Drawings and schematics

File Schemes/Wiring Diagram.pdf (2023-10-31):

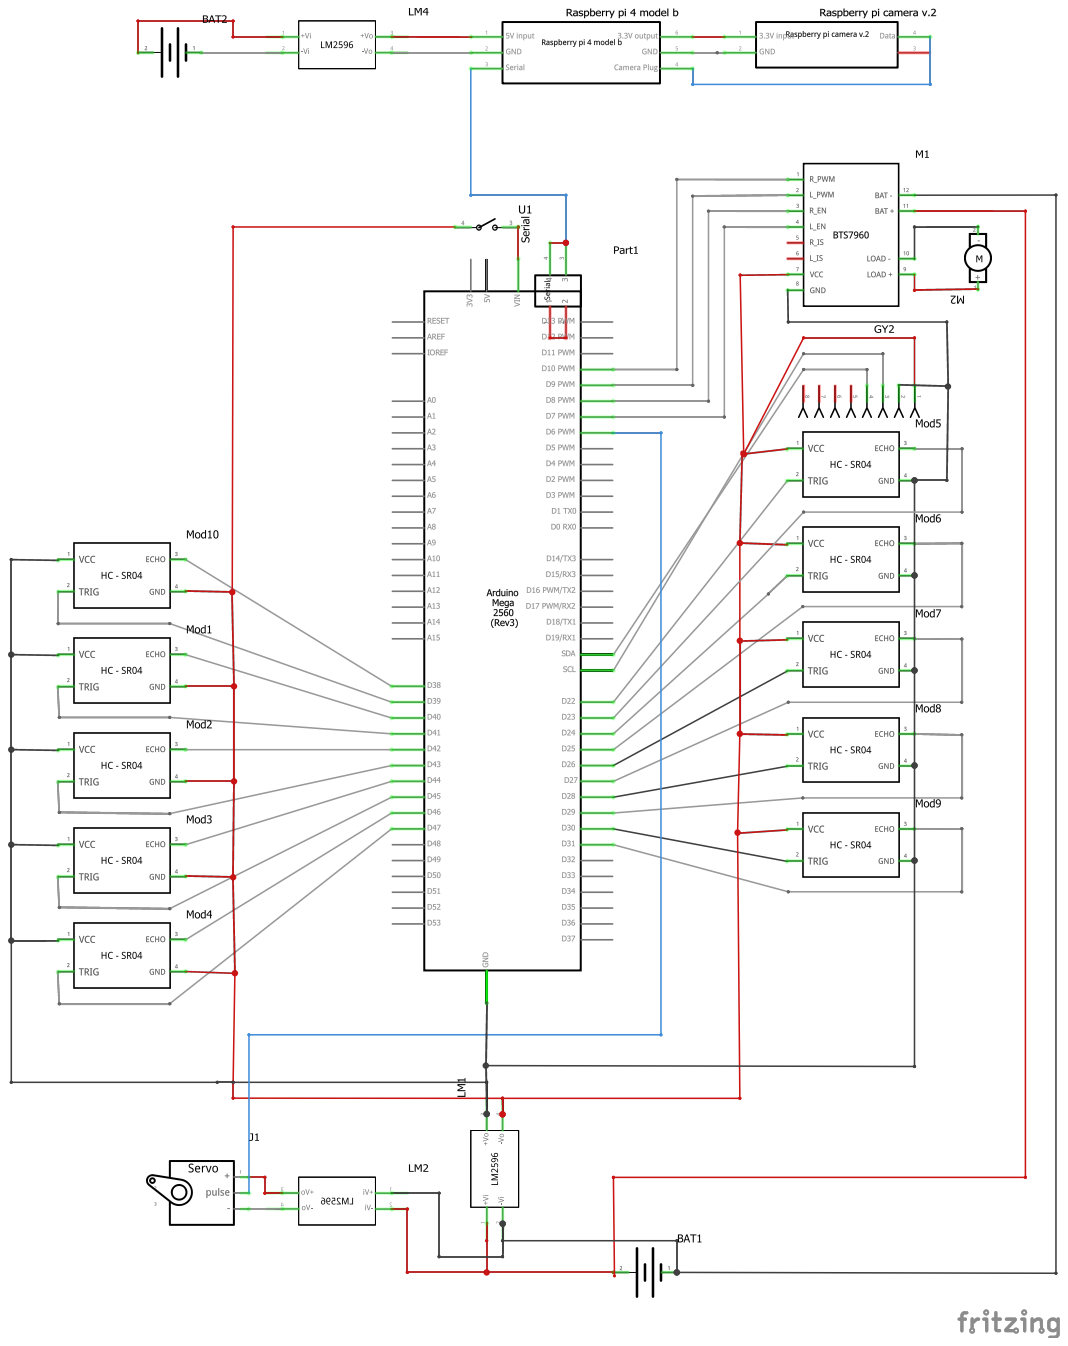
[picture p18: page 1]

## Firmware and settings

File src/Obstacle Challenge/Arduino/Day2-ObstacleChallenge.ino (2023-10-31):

#include <MPU6050_light.h>
#include <ArduinoQueue.h>
#include <NewPing.h>
#include <Servo.h>

////////////////////////////////////////////////////////////////////////////// Here is variables definition and functions declaration //////////////////////////////////////////////////////////////////////////////

#define TRIGGER_PIN_L1  34
#define ECHO_PIN_L1  35

#define TRIGGER_PIN_L2  38
#define ECHO_PIN_L2  39

#define TRIGGER_PIN_R1  23
#define ECHO_PIN_R1  22

#define TRIGGER_PIN_R2  44
#define ECHO_PIN_R2  45

#define TRIGGER_PIN_F 42
#define ECHO_PIN_F  43

#define D2R_trigger 52
#define D2R_echo 53

#define D2L_trigger 24
#define D2L_echo 25

#define B_trigger 13
#define B_echo 12

#define BL_trigger 3
#define BL_echo 2

#define BR_trigger 27
#define BR_echo 26

#define MAX_DISTANCE 300

#define R_EN 10
#define L_EN 8
#define R_PWM 11
#define L_PWM 9

#define Switch 50
MPU6050 mpu(Wire);



bool last_turn_to_R = false;
bool last_turn_to_L = false;
bool start_G =false;
bool Ana_Last = false;
int prev_section  = 2;
const double pi = acos(-1);
int pos_R = 90, pos_L = 85, pos_L_Back = 95 , pos_follow_R = 90, turn_pos = 45, turn_pos2 = 45;// TestV3
int Delay_Turn = 550;
int counter = 0;
int dis_narrow_F = 50;
int speed = 60, speed_turn = 60;
double Position_L = pos_R - turn_pos , Position_R = pos_R + turn_pos2;
double position_angle = 0;
double distance = 0, real_distance = 0 , Real_dis_L = 0, Real_dis_R = 0, dis_L1 = 0, dis_L2 = 0, dis_R1 = 0, dis_R2 = 0, dis_F = 0, dis_D2L = 0 , dis_D2R = 0 , dis_B = 0, dis_BL = 0 , dis_BR = 0  ;
double angle = 0, Angle = 0, Aangle = 0;
double conskp_R = 2.7, kp_right = 1;
double conskp = 2.2, kp_left = 1;
double Setpoint = 15;
double highest_angle = 0.27;
double pos_distance;
double jbes = 0;
double duration_F = 0, duration_L1 = 0, duration_L2 = 0, duration_R1 = 0, duration_R2 = 0 , duration_D2L = 0, duration_D2R = 0 , duration_B = 0, duration_BL = 0, duration_BR = 0;
double theta = 0, theta_mpu = 0, ref_mpu = 0; //radian
double d_pillar = 70;
double min_angle = -37 - max(pos_L, pos_R) , max_angle = 37 + max(pos_L, pos_R);
double Setpoint_Red_R = 10, Setpoint_Red_R_2 = 15;
double Setpoint_Green_L = 10, Setpoint_Green_L_2 = 15;
double counter_angle_Right = 0, counter_angle_Left = 0, counter_1 = 0;///////////123
int detected_first =  0;
char detected_cube = 'N';
char detected_P, detected_ser = 'N';
double aAngle = 0, y = 0, desired_angle = 0, Desired_angle = 0, start_angle = 0;
////////////////PID__C
double currentTime_angle = 0, dtc = 0 , lastTime_angle = 0 , current_angle = 0 , error_c = 0, output_c = 0  , last_angle_error = 0;
double kpc = 1, kdc = 1;
double reference = 0;
double reference_back = 0;
double t_make_straight;
double endReTurn = 0;
String data = "N",ser = "N" ;
int start = 0;
int i = 0;/// $£
double t_ = 0;//$£
double correction_it = 0;
double error = 0;
Servo myservo;
NewPing sonar_L1(TRIGGER_PIN_L1, ECHO_PIN_L1, MAX_DISTANCE);
NewPing sonar_L2(TRIGGER_PIN_L2, ECHO_PIN_L2, MAX_DISTANCE);
NewPing sonar_R1(TRIGGER_PIN_R1, ECHO_PIN_R1, MAX_DISTANCE);
NewPing sonar_R2(TRIGGER_PIN_R2, ECHO_PIN_R2, MAX_DISTANCE);
NewPing sonar_F(TRIGGER_PIN_F, ECHO_PIN_F, MAX_DISTANCE);
NewPing sonar_D2R(D2R_trigger, D2R_echo, MAX_DISTANCE);
NewPing sonar_D2L(D2L_trigger, D2L_echo, MAX_DISTANCE);
NewPing sonar_B(B_trigger, B_echo, MAX_DISTANCE);
NewPing sonar_BL(BL_trigger, BL_echo, MAX_DISTANCE);
NewPing sonar_BR(BR_trigger, BR_echo, MAX_DISTANCE);

int Filter_Size = 5;
double mean_bl = 0;
ArduinoQueue <double> Means_BL;
double mean_fl = 0;
ArduinoQueue <double> Means_FL;
double mean_br = 0;
ArduinoQueue <double> Means_BR;
double mean_fr = 0;
ArduinoQueue <double> Means_FR;
double mean_f = 0;
ArduinoQueue <double> Means_F;
double mean_b = 0;
ArduinoQueue<double> Means_B;

double f , fl, bl , fr , br, b;

void avoid_G(double dis = 15);
void avoid_R(double dis = 17);

void avoid_RG(double dis = 15);
void avoid_GR(double dis = 19);

////////////////////////////////////////////////////////////////////////////// End of variables definition and functions declaration //////////////////////////////////////////////////////////////////////////////


////////////////////////////////////////////////////////////////////////////// Motors controlling functions are here //////////////////////////////////////////////////////////////////////////////

void Run_Sumo (int pwm)// Move forward with "pwm" speed.
{
  digitalWrite (R_EN, HIGH);
  digitalWrite (L_EN, HIGH);
  analogWrite (R_PWM, pwm);
  analogWrite (L_PWM, 0);
}

void Stop_Sumo ()// Move backward with "pwm" speed.
{
  digitalWrite (R_EN, HIGH);
  digitalWrite (L_EN, HIGH);
  analogWrite (R_PWM, 0);
  analogWrite (L_PWM, 0);

}

void Back_Sumo (int pwm=0)//Stop the motor
{
  digitalWrite (R_EN, HIGH);
  digitalWrite (L_EN, HIGH);
  analogWrite (R_PWM, 0);
  analogWrite (L_PWM, pwm);

}

void servo_write(double ang) {// Move the servo motor "ang" degrees, set upper and lower limit for the angle.
  if (ang > max_angle) {
    ang = max_angle;
  }
  else if (angle < min_angle) {
    ang = min_angle;
  }
  myservo.write(ang);
}

////////////////////////////////////////////////////////////////////////////// End of motors controlling functions //////////////////////////////////////////////////////////////////////////////


////////////////////////////////////////////////////////////////////////////// Sensors reading functions are here //////////////////////////////////////////////////////////////////////////////
//- "Filter": This function the current reading, readings queue and last reading as input, it take the average of the last 5 readings and reutrn it as the sensor reading.

double Filter(double read, double &last_mean, ArduinoQueue <double> &Means)
{
  if (Means.isEmpty())
  {
    last_mean = read;
    for (int i = 0; i < Filter_Size; i++)
    {
      Means.enqueue(read);
    }
  }
  else
  {
    double temp = Means.dequeue();
    last_mean -= (double(temp / Filter_Size));
    last_mean += (double(read / Filter_Size));
    Means.enqueue(read);
  }
  return last_mean;
}
////////////////////////////////////////////////////////////////////////////// End of distance and angle calculation functions //////////////////////////////////////////////////////////////////////////////

double get_distance_F ()
{
  duration_F = sonar_F.ping();
  f = (duration_F / 2) * 0.0343;// Calculate the distance based on utlra sonic wave speed and time taken by the wave.
  return f;
}
double get_distance_B() {
  duration_B = sonar_B.ping();
  b = ((duration_B / 2) * 0.0343);
  return b;
}

double get_distance_BL ()
{
  duration_BL = sonar_BL.ping();
  return ((duration_BL / 2) * 0.0343);
}
double get_distance_BR ()
{
  duration_BR = sonar_BR.ping();
  return ((duration_BR / 2) * 0.0343);
}

double get_distance_L1 ()
{
  duration_L1 = sonar_L1.ping();
  fl = ((duration_L1 / 2) * 0.0343) - 4 ;
  mean_fl = Filter(fl, mean_fl, Means_FL);// Take the filtered value
  return mean_fl ;
}

double get_distance_L2()
{
  duration_L2 = sonar_L2.ping();
  bl = ((duration_L2 / 2) * 0.0343) - 4 ;
  mean_bl = Filter(bl, mean_bl, Means_BL);
  return mean_bl;
}

double get_distance_R1 ()
{
  duration_R1 = sonar_R1.ping();
  fr = ((duration_R1 / 2) * 0.0343) - 4;
  mean_fr = Filter(fr, mean_fr, Means_FR);
  return mean_fr;
}

double get_distance_R2()
{
  duration_R2 = sonar_R2.ping();
  br = ((duration_R2 / 2) * 0.0343) - 4;
  mean_br = Filter(br, mean_br, Means_BR);
  return mean_br;
}


double get_distance_D2R ()
{
  duration_D2R = sonar_D2R.ping();
  if (((duration_D2R / 2) * 0.0343) == 0)
    return 100;
  return ((duration_D2R / 2) * 0.0343);

}

double get_distance_D2L()
{
  duration_D2L = sonar_D2L.ping();
  if (((duration_D2L / 2) * 0.0343) == 0)
    return 100;
  return ((duration_D2L / 2) * 0.0343) - 3 ;
}

////////////////////////////////////////////////////////////////////////////// End of sensors reading functions //////////////////////////////////////////////////////////////////////////////

////////////////////////////////////////////////////////////////////////////// Distance and angle calculation functions are here //////////////////////////////////////////////////////////////////////////////
/*
The provided functions below are responsible for all mathematical calculations (angle, prependicular distance,filtering):
- "Distance": Takes distance sensors readings as input, and returns the prependicular distance.
- "angle_cal": Takes sensor readings as input, and returns the angle between the robot and the wall.
- "correction_L"/"correction_R": Those functions are responsible for correcting the MPU6050 input reference, they work by taking the average of 5 angle calculations and substracting the value from the calculated reference.
- "reset_means": Resets the sensors readings queues, this is necessary when moving from corner section to straight forward section (Values may some time to be updated due to the nature of filtering, thus, resetting them is beneficial).
*/

  double angle_cal (double dis_1 , double dis_2)
{
  Angle =  atan ((dis_1 - dis_2 ) / 7.5);
  if (Angle > highest_angle)
  {
    Angle =  highest_angle;
  }
  if (Angle < ((-1)*highest_angle))
  {
    Angle = (-1) * highest_angle;
  }
  return Angle;
  //Radian
}
double Distance(double L1 , double L2)
{
  distance = (L1 + L2) / 2;
  angle = angle_cal (L1, L2);
  real_distance = distance * cos(angle);
  return real_distance;
}
void correction_L(){
   if(correction_it == 4){
      reference -= error/5;
      error = 0;
    }
    else {
      error += angle_cal(dis_L1,dis_L2)*180/acos(-1);
      correction_it++;
    }
}
void correction_R(){
   if(correction_it == 4){
      reference -= error/5;
      error = 0;
    }
    else {
      error += angle_cal(dis_R1,dis_R2)*180/acos(-1);
      correction_it++;
    }
}
void reset_means()
{
 while (!Means_B.isEmpty())
 {
   Means_B.dequeue();
   Means_BL.dequeue();
   Means_BR.dequeue();
   Means_FL.dequeue();
   Means_FR.dequeue();
   Means_F.dequeue();

 }
}


double angleR = 0, angleL = 0;
void sensor() {
  dis_R1 = get_distance_R1();
  delay(10);
  dis_L2 = get_distance_L2();
  delay(10);
  dis_B = get_distance_B();
  delay(10);
  dis_L1 = get_distance_L1();
  delay(15);
  dis_R2 = get_distance_R2();
  delay(15);
  dis_F = get_distance_F();
  delay(10);
  Real_dis_L = Distance(dis_L1, dis_L2);
  Real_dis_R = Distance(dis_R1, dis_R2);

  angleR = angle_cal(dis_R1, dis_R2) * 180 / pi;
  angleL = angle_cal(dis_L1, dis_L2) * 180 / pi;

}
////////////////////////////////////////////////////////////////////////////// Motion in protected area and unprotected area functions are here //////////////////////////////////////////////////////////////////////////////

/*
 The functions that drive the motion in the protected and unprotected areas are presented here:
- ("angle_Left","angle_Left_Back","angle_Right","angle_FollowR"): These functions are repsonsible for PID following with ki and kd constants equal to zero, they use the angle calculated using sensors readings. These functions differ
in the setpoint and used sensors.
- ("P_distanceL","P_distanceR"): These functions work by the same manner, but with a higher kp constant.
- "PID_angle"/"PID_angle_Back": hese functions are repsonsible for PID following with ki constant equal to zero, they use the input angle from the gyroscope sensor. 
*/

double angle_Left(double L1 , double L2) {


  angle =  angle_cal (L1, L2);

  Angle = (angle * 180) / 3.14;

  position_angle = pos_L - Angle;

  myservo.write(position_angle);

}
double angle_Left_Back(double L1 , double L2) {


  angle =  angle_cal (L1, L2);

  Angle = (angle * 180) / 3.14;

  position_angle = pos_L_Back - Angle;

  myservo.write(position_angle);

}

double angle_Right(double R1 , double R2) {

  angle =  angle_cal (R1, R2);

  Angle = (angle * 180) / 3.14;

  position_angle = pos_R + Angle;

  myservo.write(position_angle);

}
double angle_FollowR(double R1 , double R2) {


  angle =  angle_cal (R1, R2);

  Angle = (angle * 180) / 3.14;

  position_angle = pos_follow_R + Angle;

  myservo.write(position_angle);

}

double P_distanceL (double real_distance , double Set_Point)
{
  pos_distance = conskp * (real_distance - Set_Point);
  jbes = pos_L - pos_distance;
  servo_write(jbes);
}
double P_distanceR (double real_distance , double Set_Point)
{
  pos_distance = conskp_R * (real_distance - Set_Point);
  jbes = pos_R + pos_distance;
  servo_write(jbes);
}

void Back_PID_angle(double current_angle) {
  currentTime_angle = (micros()) * (1e-3);
  dtc =  currentTime_angle - lastTime_angle;
  lastTime_angle = currentTime_angle;
  error_c = current_angle - reference_back;
  output_c = kpc * error_c + ((error_c - last_angle_error) / dtc) * kdc ;
  servo_write( pos_R - output_c);
  last_angle_error = error_c;
}
void PID_angle(double current_angle) {
  currentTime_angle = (micros()) * (1e-3);
  dtc =  currentTime_angle - lastTime_angle;
  lastTime_angle = currentTime_angle;
  error_c = current_angle - reference;
  output_c = kpc * error_c + ((error_c - last_angle_error) / dtc) * kdc ;
  servo_write(output_c + pos_R);
  last_angle_error = error_c;
}

////////////////////////////////////////////////////////////////////////////// End of motion in protected area and unprotected area functions //////////////////////////////////////////////////////////////////////////////


////////////////////////////////////////////////////////////////////////////// Following functions are described and explained here //////////////////////////////////////////////////////////////////////////////

/*
Following functions are explained below, each function works in the same manner. we will refer to the unprotected area by "UPA" and protected area by "PA":
1- If the prependicular distance is small (<5cm), this means that the robot is in the UPA. The program calls "P_distanceR"/"P_distanceL" functions depending on which side is the robot. Those functions are responsible for 
keeping the robot away from UPA by using P algorithm with relatively big P constant.
2- If the previous condition is not true for the two sides, this means that the robot is in PA. "PID_angle" function is called in "followmiddle_straight" function, which applies PD algorithm on robot's angle to keep it parallel to the wall.
On the other hand, the rest of following functions call ("angle_Left","angle_Right","angle_FollowR"), this difference comes from the fact that "followmiddle_straight" function is called in the first turn, which means that
the direction of movement is not identified yet, thus applying PD algorithm on one of the algorithms ("angle_Left","angle_Right","angle_FollowR") may result in unstable movement (In case of reading distances from a long distance, the measurments won't be precise).

*/
void followmiddle_straight()
{
   if (Real_dis_R < 5)
  {
    P_distanceR(Real_dis_R, 5);
  }
  else if (Real_dis_R > 90)
  {
    P_distanceR(Real_dis_R, 90);
  }
  else
  {
      if(counter_angle_Right == 1)correction_R();
      if(counter_angle_Left == 1)correction_L();
      mpu.update();
      PID_angle(mpu.getAngleZ());
 }
}
void follow_G_Counter() {
  Ana_Khales();
  while (true) {

    sensor();
 
    if (counter_angle_Right == 1 && fl >= 50)break;
    if(((counter_angle_Left == 0 && counter_angle_Right == 0) || counter_angle_Left == 1)  && (fr > 100 || fl > 100))break;
    if (Real_dis_L < 13)
    {
      Run_Sumo(speed);
      P_distanceL(Real_dis_L, 13);
    }
    else if (Real_dis_L > 16)
    {
      Run_Sumo(speed);
      P_distanceL(Real_dis_L, 16);
    }
    else
    {
      Run_Sumo(70);
      angle_Left(fl, bl);
    }
    if (Serial.available() > 0) {
      data = Serial.readStringUntil('#');
    }
  }

if(counter_angle_Right == 1)
{
  servo_write(pos_R);
  mpu.update();
  reference = mpu.getAngleZ();
  for(int i=0;i<50;i++)
  {
    delay(10);
    mpu.update();
    PID_angle(mpu.getAngleZ());
  }
}
  detected_cube = 'G';
  detected_ser = 'N';
}
void follow_G_cw()
{

  servo_write(pos_R);
  while (true) {
   
    sensor();
    angle_Left(dis_L1, dis_L2);
    if (fr < 100 && dis_B > 80)break;

  }

  detected_cube = 'G';
  detected_ser = 'N';
}
void follow_G_cww() {
  sensor();
  servo_write(pos_R);
  while (true) {
    
    sensor();
    angle_Right(fr, br);
    if (bl < 40 && dis_B > 80)break;

  }

  detected_cube = 'G';
  detected_ser = 'N';
}
void follow_G_GN() {
  Ana_Khales();

 
  while (true) {

    sensor();
    if (counter_angle_Right == 1 && fl >= 50)break;
    if(((counter_angle_Left == 0 && counter_angle_Right == 0) || counter_angle_Left == 1)  && (fr > 100 || fl > 100))break;    
    
    
    if (Real_dis_L < 7)
    {
      Run_Sumo(speed);
      P_distanceL(Real_dis_L, 7);
    }
    else if (Real_dis_L > 17)//15 $
    {
      Run_Sumo(speed);
      P_distanceL(Real_dis_L, 17);//13 $
    }
    else
    {
      Run_Sumo(70);
      angle_Left(fl, bl);
    }
    if (Serial.available() > 0) {
      data = Serial.readStringUntil('#');
    }
  }
  if(counter_angle_Right == 1)
  {
  servo_write(pos_R);
  mpu.update();
  reference = mpu.getAngleZ();
  for(int i=0;i<50;i++)
  {
    delay(10);
    mpu.update();
    PID_angle(mpu.getAngleZ());
  }
  }
         
  detected_cube = 'G';
  detected_ser = 'N';
}
void follow_R_cw()
{  
  servo_write(pos_R);
  while (true) {
    sensor();
    if (br < 40 && dis_B > 80)break;
    angle_Left(fl, bl);
  }
  detected_cube = 'R';
  detected_ser = 'N';
}
void follow_R_Counter() {
  Ana_Khales();
  while (true) {

    sensor();
    if(counter_angle_Left == 1 && fr > 50)break;
    if(((counter_angle_Left == 0 && counter_angle_Right == 0) || counter_angle_Right == 1) && (fr > 100 || fl > 100))break;
    if (Real_dis_R < 7 )
    {
      Run_Sumo(speed);
      P_distanceR(Real_dis_R, 7);
    }
    else if (Real_dis_R > 14)
    {
      Run_Sumo(speed);
      P_distanceR(Real_dis_R, 14);
    }
    else
    {
      Run_Sumo(70);
      angle_FollowR(fr, br); 
    }
  }
  if(counter_angle_Left == 1)
  {
  servo_write(pos_R);
  mpu.update();
  reference = mpu.getAngleZ();
  for(int i=0;i<50;i++)
  {
    delay(10);
    mpu.update();
    PID_angle(mpu.getAngleZ());
  }
  }
  detected_cube = 'R';
  detected_ser = 'N';
}
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
void loop() {
  if(counter_1 == 0)// This code block is only true when the arduino code begins, it keeps the code in an open loop until start switch is on.
  {
      while (start == 0)
    {
      start = digitalRead(Switch);
      if (Serial.available() > 0) {/// Check whether arduino recieved from Raspberry Pi through serial communication.
        // debug();
        data = Serial.readStringUntil('#');
      }
      delay(1);
    }
  }
  Run_Sumo(speed);
  if (counter_1 >= 12)
  {
    Stop_Sumo();
    delay(100000000);
  }

  sensor();
  if (loop_start_pos) { //This code block also works only at the start of the program, it sets the servo angle to the setpoint and set an mpu reference.
    servo_write(pos_R);
    loop_start_pos = 0;
    mpu.update();
    reference = mpu.getAngleZ();
  }
  if (Serial.available() > 0) {/// Check whether arduino recieved from Raspberry Pi through serial communication.
    data = Serial.readStringUntil('#');
    Run_Sumo(speed);
  }
  if (data == "R" || data == "RG" || data == "RR") {/// Check the stored value in "data" string in the beginning of the round, if the recived data is one of the following characters ("R","RG","RR"), this means that there is a red pillar in the current section to be avoided (ignore the one in the next section in case it is recieved since the algorithm cares about the pillars in the current section only).
    avoid_R();
  }
  else if (data == "G" || data == "GR" || data == "GG") {/// Check the stored value in "data" string in the beginning of the round, if the recived data is one of the following characters ("G","GR","GG"), this means that there is a red pillar in the current section to be avoided (ignore the one in the next section in case it is recieved since the algorithm cares about the pillars in the current section only).
     start_G = true;
    avoid_G();
  }

  else {// Raspberry Pi did not detect any pillar, move straight (followmiddle_straight).
    if (Real_dis_R < 100 && Real_dis_L < 100) {
    
      followmiddle_straight();
    }
  }
  if (counter_angle_Left == 0 && counter_angle_Right == 0 ) {// If the robot did not detect any turn yet (direction of movement is not identified yet).
    if (fl > 100 || bl > 100) {// If one of the left sensors detects a large distance (>100cm), then turn left.

      Turn_L_Back();

    }
    if (fr > 100 || br > 100) {// If one of the right sensors detects a large distance (>100cm), then turn right.
      Turn_R_Back();

    }
  }
  if (counter_angle_Right == 1) {// If the direction of movement is counter clockwise (CCW).
    if ((fl > 100 || bl > 100)&&b>190&&detected_cube=='N') {// If one of the left sensors detects a large distance (>100cm),the robot is in the end of the current section (b>190cm) and no pillars were detected, then turn left.
      Turn_L_Back();
    }
    else if ((fl > 100 || bl > 100)&&(detected_cube == 'R' || detected_cube == 'G'))// If one of the right sensors detects a large distance (>100cm) and the robot avoided one of the pillars, then it is the end of the current section and it has to turn left.
      Turn_L_Back();
    }
  if (counter_angle_Left == 1) {// If the direction of movement is clockwise (CW).
    if ((fr > 100 || br > 100)&&b>190&&detected_cube == 'N') {// If one of the right sensors detects a large distance (>100cm),the robot is in the end of the current section (b>190cm) and no pillars were detected, then turn right.
      Turn_R_Back();
    }
    else if ((fr > 100 || br > 100)&&(detected_cube == 'R' || detected_cube == 'G')) {// If one of the right sensors detects a large distance (>100cm) and the robot avoided one of the pillars, then it is the end of the current section and it has to turn right.
      Turn_R_Back();
    }
  }
}

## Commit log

2023-08-31 Chassis Design
2023-08-31 Coupler Design uploaded
    [Coupler.CATPart]
2023-08-31 rename: 3d chassis
2023-09-13 Readme update: Why Jsumo Motor?
2023-09-13 Readme update: Sense & Power Management (E components)
2023-09-13 power supply
2023-09-16 Readme update: E-components (Arduino mega board)
2023-09-16 Readme update: E-components (Raspberry pi 4 model B)
2023-10-19 Arduino Code for obstacle challenge
2023-10-31 Wiring Diagram uploaded
    [Wiring.fzz]
2023-10-31 BOM uploaded
2023-10-31 BOM.md uploaded
2023-10-31 side + cieling cover CATIA V5 Design uploaded
    [Assembly Side+Cieling Cover.CATProduct, cieling.CATPart, side.CATPart]
2023-10-31 side + cieling cover CATIA V5 Design updated
    [Assembly Side+Ceiling Cover.CATProduct]
2023-10-31 models requiements updated
    [Assembly Side+Ceiling Cover.CATProduct, Coupler.CATPart, cieling.CATPart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]
